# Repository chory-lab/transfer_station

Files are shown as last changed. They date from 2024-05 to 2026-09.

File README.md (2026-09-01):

[comment]: <> (Author: Benjamin Pyatski)
[comment]: <> (Company: Chory Lab)

<h1>Introduction</h1>
This repository holds the code (and previously used test code) for the functioning of the transfer system, or just the step motor rail. There are two parts to this README detailing the software components, and the hardware components of the transfer station system.

<h2>SD Card Setup</h2>

This branch publishes a complete, CI-audited Raspberry Pi OS image with the
application, Redis, frozen Python environment, systemd service and isolated
network configuration already installed. The flashers verify its SHA-256.

<h3>Windows</h3>

Insert the SD card, then paste into an <b>Administrator</b> PowerShell:

```powershell
irm https://raw.githubusercontent.com/chory-lab/transfer_station/main/pi-image/bootstrap.ps1 | iex
```

To select a physical disk number explicitly, download the script first:

```powershell
irm https://raw.githubusercontent.com/chory-lab/transfer_station/main/pi-image/bootstrap.ps1 -OutFile bootstrap.ps1
.\bootstrap.ps1 -DiskNumber 3
```

The media can be blank. Requires
<a href="https://www.raspberrypi.com/software/">Raspberry Pi Imager</a> to be
installed; Imager writes and verifies the complete prebuilt image.

<h3>macOS / Linux</h3>

Insert a removable SD card or USB drive and run:

```bash
curl -fsSL https://raw.githubusercontent.com/chory-lab/transfer_station/main/pi-image/bootstrap.sh | sudo bash
```

On macOS, install
<a href="https://www.raspberrypi.com/software/">Raspberry Pi Imager</a> first;
the script uses it to write and verify the selected external disk. Linux uses
the standard <code>lsblk</code>, <code>xz</code>, and <code>dd</code> tools.

<h3>Then: wire up the controller PC</h3>

The script asks which removable device to erase, downloads the audited sdm
image, verifies its checksum, and writes it. <b>No internet is needed on the
Pi.</b>

The Pi is reachable only over a private wired link, and <b>nothing on that
link hands out addresses</b>, so the controller PC's wired adapter must be
given a static address. Connect an Ethernet cable between the PC and the Pi,
then give the PC's wired adapter any address in <code>192.168.10.0/24</code>
except <code>192.168.10.1</code> (the Pi itself) &mdash; the convention is
<code>192.168.10.2</code> &mdash; with <b>no gateway and no DNS</b>. Leave
the PC's Wi-Fi or other adapters alone so it keeps its own internet.

Windows (Administrator PowerShell; replace <code>Ethernet</code> with the
wired adapter name shown by <code>Get-NetAdapter</code>):

```powershell
New-NetIPAddress -InterfaceAlias Ethernet -IPAddress 192.168.10.2 -PrefixLength 24
```

macOS (replace <code>en5</code> with the wired interface from
<code>networksetup -listallhardwareports</code>):

```bash
sudo ifconfig en5 192.168.10.2/24
```

Linux (replace <code>eth0</code> with the wired interface from
<code>ip -br link</code>):

```bash
sudo ip addr add 192.168.10.2/24 dev eth0
```

The Pi then comes up at:

```
http://192.168.10.1:5000        ssh chorylab@192.168.10.1
```

This branch currently uses the image build credential. Until the
<code>PI_PASSWORD</code> repository secret is configured and a new image is
published, the password is <code>changeme</code>. Change it after login.

<blockquote>
The image targets a Pi 4 Model B and works from SD or USB mass storage when
the Pi EEPROM permits USB boot. Do not apply Raspberry Pi Imager OS
customisation: the image is already configured. See
<a href="pi-image/README.md">pi-image/README.md</a> for internals and limits.
</blockquote>

<h2>Software</h2>
This section details the usage of the code.

<h3>api_step_motor.py</h3>
The system is setup in such a way where the majority of the fucntional code is in api_step_motor, which creates a UI through flask (and handles subsequent interactions with said UI) that the user can input commands to. 

<h3>A4988.py</h3>
In order for the stepper motor to connect to the Raspberry Pi 4 it is necessary to utilize a A4988 controller, and the python file of the same name holds all the function definitions utilized in api_step_motor.py and the microswitches, and handles the connection between the Raspberry Pi 4 and the stepper motor on the rail.

<h3>FLow Chart</h3>



<h2>Manual Setup (alternative to flashing)</h2>

<h3>Installation</h3>

* Install flask (make sure it is ver 2.2.2 or newer otherwise --app feature won't work, check this by running flask --version):
  
    ```pip install --upgrade Flask ```

* Install reddis:

    ```pip install redis```

* Install flask_caching:
  
    ```pip install flask_caching```

<h3>Setup (Skip if setup already running)</h3>
The first step is to get start the flask and redis server, the redis server handling multiple calls at the same time to allow asynchronous running of the code. 
<br><br>

1. Activate the Virtual Environment
    - Navigate to the location of the virtual environment:
    
      ```cd /home/git/transfer_station```
    - Activate the virtual environment:
    
      ```source foobar/bin/activate```
    
2. In another terminal, start the redis server:
   
    ```redis-server```  

4. Run the code through flask (on the previously setup virtual environment) and open the outputted link (first one is for the local machine, second is for a different machine on the same wifi):

    ```flask --app api_step_motor run --host=0.0.0.0```

<h2>Hardware</h2>
The hardware can be categorized into two parts, the actual circuitry required to run the transfer station, and then the physical components that actually make up the parts of the transfer station itself. 

<h3>Transfer Station Circuitry</h3>
The transfer station consists of a step motor rail connected through a motor driver (A4988 Stepper Motor Driver) to a computer (Raspberry Pi Zero 2 W) on which the code is running. The wiring diagram can be seen below:

![image](https://github.com/chory-lab/transfer_station/assets/69654071/a2e29e91-b305-4fbc-8b5c-8c84075bc933)

<h4>A4988 Stepper Motor Driver</h4>

![image](https://github.com/chory-lab/transfer_station/assets/69654071/13c0050c-7d20-4bd9-b880-a7aa17810c33)

Pin Index:
  - ENA -> Enable pin. When low A4988 is enabled, when high A4988 is disabled
  - RES -> Reset pin
  - SLP -> Sleep pin (connected to RES so SLP triggers code RES)
  - STP -> Step. Reads how many steps requested for the step motor to take
  - DIR -> Direction.
  - VMT -> Energy supply to power step motor
  - GND -> Ground
  - 2B, 2A, 1A, 1B -> Control for Bipolar Step Motor (Power, Step, Direction)
  - VDD -> Power for A4988

<h4>Raspberry Pi Zero 2 W</h4>

![image](https://github.com/chory-lab/transfer_station/assets/69654071/397a1f29-71f6-4400-840c-6d2acba378ad)

![image](https://github.com/chory-lab/transfer_station/assets/69654071/97159fb8-87ad-45c7-b7d0-eb24ef14be5d)

Pin Index:
  - 2 -> 5V Power to supply A4988
  - 6 -> Ground
  - 15 -> GPIO22, programmable pin
  - 16 -> GPIO23, programmable pin
  - 18 -> GPIO24, programmable pin

Any GPIO can be used as they are all programmable

<h3>Transfer Station System</h3>
The system is composed of 4 core components, these consist of the tray, tray platform, step motor rail system, and the mount. All components were printed with PLA plastic, and default 3D printer settings. Screws used were the default ones that come with the Hamilton Star, and the default bolts that came with the incubator mount. 

<h4>Tray</h4>
This is holds the 96 well plate (or equivalent size) when delivering the plate to the incubator, and vice versa.

![image](https://github.com/chory-lab/transfer_station/assets/69654071/5e6d066a-dbb4-403d-9bdd-c4cc44f140a3)

<h4>Tray Platform</h4>
This raises the tray to the needed height for the incubator to be able to reach the plate.

![image](https://github.com/chory-lab/transfer_station/assets/69654071/3565bda2-becf-4eeb-828e-3ba721c507a8)

<h4>Stepper Motor Rail System</h4>
This comprises of a stepper motor, connected to a rail system (screw) that spins moving a cart that is already on the screw.

![image](https://github.com/chory-lab/transfer_station/assets/69654071/2178c803-b7bc-447f-a207-de881839ab26)

<h4>Mount</h4>
This is what the stepper motor rail system is screwed onto connecting/supporting the stepper motor rail system on the incubator.

![image](https://github.com/chory-lab/transfer_station/assets/69654071/8c9b438e-2e05-4f78-83f6-389a6350ffdf)

<h4>Assembly</h4>
The final assembly consists of:

  1. Screw mount onto incubator with M6 x 12mm screws (x2)

  2. Screw stepper motor rail system to the mount with M3 x 12mm screws (x4)
  
  3. Screw tray platform onto cart with M4 x 8mm screws (x4)
  
  4. Slide tray onto pegs on tray platform
  
![image](https://github.com/chory-lab/transfer_station/assets/69654071/2ea4342a-1d0f-4a60-ac54-e75c83075aa1)

![IMG_2489](https://github.com/chory-lab/transfer_station/assets/69654071/6cb466e3-b27b-4c4f-b220-d72cb4b66d85)

<h2>Parts List</h2>
1. 3D Printed Pieces

  - Mount
  
  - Tray

  - Tray Stand
<br>
2. Screws

  - M6 x 12mm (x2) -> Used for screwing mount onto incubator
    - https://www.amazon.com/PZRT-Hexagon-Socket-Countersunk-Stainless/dp/B08DF82569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

  - M4 x 8mm (x4) -> Used for screwing tray platform onto cart
    - https://www.amazon.com/Socket-Screws-Metric-Machine-Threaded/dp/B0969NLFKW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

  - M3 x 12mm (x4) -> Used for screwing rail onto mount
    - https://www.amazon.com/SUNXULIMI-Socket-Furniture-Stainless-Threaded/dp/B0CMDVK2QK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
<br>

3. A4988 Stepper Motor Drive -> Needs seperate power cable
  - https://www.amazon.com/WWZMDiB-Stepstick-Stepper-Printer-Suitable/dp/B0BFQZWT6R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
<br>

4. Raspberry Pi Zero 2 W -> Needs seperate power cable, and male header pins to solder on
  - https://www.amazon.com/Raspberry-Quad-core-Bluetooth-onboard-Antenna/dp/B0CCRP85TR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

5. Stepper Motor Rail System
  -  https://www.amazon.com/FUYU-Linear-Module-Actuator-Stepper/dp/B0CG5PPKXY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

6. Powered USB hub with mini USB connector -> Used for connecting keyboard and mouse to raspbery pi zero 2 w
  - https://www.amazon.com/AuviPal-Adapter-Playstation-Classic-Raspberry/dp/B083WML1XB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

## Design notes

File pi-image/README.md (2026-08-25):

# pi-image

Builds a ready-to-flash Raspberry Pi image with the application, its
dependencies, an autostarting service, and an isolated static-IP ethernet
link all baked in.

Flash it and switch the Pi on. There is no first-boot provisioning, no
two-stage boot, and **the Pi never needs a network**.

## Why this shape

The obvious approach is to flash stock Raspberry Pi OS and configure it on
first boot. We built that first, and it cost us: a `systemd.run=` hook whose
path depends on the OS release, Windows volumes that sometimes have no drive
letter, CRLF mangling the shebang of the first-boot script, a Pi with no RTC
whose clock made `apt` reject repositories, and a 23 MB dependency bundle to
avoid needing internet on the device.

Every one of those problems exists only because work was deferred to the
device. Doing it at build time, in a chroot on a machine that can be tested,
deletes the entire category.

[`sdm`](https://github.com/gitbls/sdm) does the image customisation. It
already handles the account wizard, cloud-init, `machine-id`, root expansion
and the rest — the things we would otherwise rediscover one bug at a time.

## Building

```bash
sudo PI_PASSWORD='your-password' ./pi-image/build.sh
```

Produces `transfer-station-YYYY-MM-DD.img.xz` (currently about 900 MB). Flash it with
Raspberry Pi Imager, with **no customisation** — this image already has it.

CI builds and audits the final compressed image on every relevant push. Main
publishes the rolling `pi-image` release; the top-level README flashers
download that exact asset and verify its checksum.

## Configuring

Everything project-specific is in [`pi-app.env`](pi-app.env). That file is
the entire interface:

| Key | Meaning |
|---|---|
| `APP_NAME`, `PI_HOSTNAME`, `PI_USER` | identity |
| `REPO_DEST` | where the app is installed |
| `APT_PACKAGES` | system packages (C extensions, services) |
| `APP_EXEC` | the command the service runs; `${VENV}` and `${SERVER_PORT}` are substituted |
| `ETH_*`, `SERVER_PORT` | the isolated link |

Pure-Python dependencies come from `pyproject.toml` and are installed from
the hash-pinned `uv.lock` with `uv sync --frozen`
into a venv built on the system interpreter with `--system-site-packages` so
apt's prebuilt `RPi.GPIO` stays importable.

> **Never commit a real password.** This repository is public. Pass
> `PI_PASSWORD` in the environment, or set `PI_SSH_PUBKEY` and use a key.

## Using it for another instrument

Copy `pi-image/` and write a new `pi-app.env`. `build.sh`, `cscript.sh` and
the CI workflow are project-agnostic; only the manifest changes.

## The isolated link

`eth0` gets a static address with **no gateway and no DNS**, plus
`never-default=true` and IPv6 disabled. Without a default route on that
interface the Pi cannot reach, or be reached from, the lab LAN — only hosts
plugged into the same switch.

The controller PC needs a static address on the same subnet with no gateway
(e.g. `192.168.10.2/24`). Leave its normal Wi-Fi/LAN adapter alone so it
keeps its own default route and stays online.

## How it works

`build.sh` downloads the official Raspberry Pi OS Lite image, renders the
service unit and NetworkManager profile from the manifest, and hands the lot
to `sdm`, which runs [`cscript.sh`](cscript.sh) in three hooks:

- **phase 0** — on the host, image mounted at `$SDMPT`. Copies the repo, the
  service unit and the network profile in.
- **phase 1** — inside the image under `nspawn`. Installs `uv`, builds the
  This hook is deliberately empty because sdm has not created the user or
  installed apt packages yet.
- **post-install** runs inside the image after sdm's plugins. It installs
  `uv`, performs `uv sync --frozen`, verifies the imports, and enables the
  service and SSH.

Then the image is compressed, decompressed again, mounted, and audited before
publication. CI checks the real filesystem, packages, venv, enabled services,
boot layout and the no-gateway/no-DNS static network profile.

## Limits

- Linux only. `sdm` mounts and chroots into the image.
- Needs `qemu-user-static` binfmt for aarch64 when building on x86.
- The venv is built under emulation, so `RPi.GPIO` is checked by spec rather
  than imported — it raises on non-Pi hardware by design.
- Updating a deployed Pi means either re-flashing or copying files over SSH.
  SSH is enabled precisely so re-flashing is not the only option.

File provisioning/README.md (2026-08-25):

# Transfer Station SD card provisioning

Turns a stock Raspberry Pi OS Lite image into a ready-to-run transfer station:
the repo installed, the Flask server started automatically at boot, and `eth0`
pinned to a static address on an **isolated** ethernet segment.

## What you end up with

| | |
|---|---|
| UI | `http://192.168.10.1:5000` |
| SSH | `ssh chorylab@192.168.10.1` |
| Server | `systemd` unit `transfer-station.service` (auto-restarts on failure) |
| Logs | `journalctl -u transfer-station -f` |

`eth0` gets a static address with **no gateway and no DNS**. Without a default
route on that interface the Pi cannot reach — and cannot be reached from — the
lab LAN. It is visible only to hosts plugged into the same switch.

Edit `config.env` before flashing to change the address, port, hostname or
password.

## Flashing

### Windows

Flash the base image with Raspberry Pi Imager first, then:

```powershell
.\provisioning\flash.ps1
```

It finds the card by looking for the FAT32 volume that has a `cmdline.txt` in
it. Pass `-BootDrive E:` when more than one card is attached and you want to
name the right one; `E:` is the small FAT partition Windows mounts after
imaging (the one with `config.txt` and `cmdline.txt` in it).

#### If the boot partition has no drive letter

Windows does not always assign one. Disk Management then shows the partition
under its `bootfs` label with the drive-letter column blank, and nothing --
not `tar`, not PowerShell's own `New-Item` -- can write to it, because the
only path it has is a `\\?\Volume{GUID}\` path that those tools reject.

Both `flash.ps1` and `bootstrap.ps1` still *find* such a card, and will assign
a free letter themselves if PowerShell was started with **Run as
administrator**. Without elevation they stop and say so; assign the letter by
hand instead:

> Win+X -> Disk Management -> right-click the `bootfs` partition ->
> Change Drive Letter and Paths -> Add -> OK

### Which image, and Raspberry Pi Imager's customisation

Lite 64-bit is the intended base, but Desktop and Full work too -- nothing
here depends on the absence of a GUI.

Current Imager versions provision through **cloud-init**: applying any OS
customisation writes `user-data`, `meta-data` and `network-config` to the boot
partition and appends `ds=nocloud;...` to `cmdline.txt`. That is compatible
with the two-stage flow, but cloud-init runs *after* stage A and wins wherever
the two overlap:

| Setting | Winner on a customised card |
|---|---|
| hostname | Imager's, not `PI_HOSTNAME` |
| account password | Imager's, not `PI_PASSWORD` |
| SSH enabled | both do it |
| isolated static IP | stage B (its profile has `autoconnect-priority=100`) |

So either leave Imager's customisation switched off and let `config.env` own
everything, or set it in Imager and treat `PI_HOSTNAME` and `PI_PASSWORD` as
ignored. Stage B is ordered `After=cloud-final.service`, so the two never
contend for the apt lock.

### Linux / macOS

```bash
# flash and provision in one go
sudo ./provisioning/flash.sh --image raspios-bookworm-arm64-lite.img.xz --device /dev/sdX

# or provision a card you already flashed
./provisioning/flash.sh --boot /media/$USER/bootfs
```

## Troubleshooting a failed first boot

Both stages write a log to the **FAT boot partition**, which mounts on any
machine. If a boot goes wrong, pull the SD card, put it in your laptop and
read:

```
transfer-station/firstrun.log    # stage A
transfer-station/provision.log   # stage B
```

Stage B also prints to the console, so an HDMI monitor shows it live.

If stage A or B fails, the Pi falls back to DHCP with SSH enabled. Note that
on the isolated switch there is **no DHCP server**, so it will land on a
link-local `169.254.x.x` address and be effectively unreachable — plug it back
into a router to recover it over the network.

## First boot: plug into the internet once

The card boots in three phases:

1. **Stage A** (`firstrun.sh`, no network) — creates the user, sets the
   hostname, enables SSH, unpacks the repo, arms stage B. Reboots.
2. **Stage B** (`provision.sh`, needs internet) — `apt` installs
   `redis-server` and `python3-rpi.gpio`, installs `uv`, builds the venv,
   installs the systemd unit, then writes the isolated static network config.
   Reboots.
3. **Normal operation** — isolated static IP, server running.

Stage B is the only step that needs internet, so **give the Pi a normal
router/switch connection for the first boot**. It takes a few minutes. Once it
reboots into phase 3 you can move it to the isolated switch permanently.

If stage B can't reach the internet it exits with a clear error and retries on
the next boot — nothing is lost, just reconnect and reboot.

## Controller PC setup

Give the NIC facing the switch a static address on the same subnet, no gateway:

```
address 192.168.10.2
netmask 255.255.255.0
gateway <blank>
```

Leave your normal Wi-Fi/LAN adapter alone — it keeps the default route, so the
PC keeps internet while talking to the Pi over the switch.

## Python environment

`uv` manages the pure-Python deps in `pyproject.toml` and the frozen `uv.lock`.
The venv is built on
the **system** interpreter with `--system-site-packages`, so the apt-provided
`RPi.GPIO` C extension stays importable:

```bash
uv venv --python /usr/bin/python3 --system-site-packages .venv
UV_PROJECT_ENVIRONMENT=.venv uv sync --frozen --no-dev
```

To update deps on a running unit:

```bash
cd /home/chorylab/transfer_station
UV_PROJECT_ENVIRONMENT=.venv uv sync --frozen --no-dev
sudo systemctl restart transfer-station
```

The old `foobar/` venv (Python 3.7.3) is not used by the image and can be
ignored.

## Tests

```bash
provisioning/tests/run-all.sh              # host-safe suites
sudo provisioning/tests/run-all.sh         # + loopback SD card write
pwsh provisioning/tests/test_flash_ps1.ps1 # Windows flasher
```

| Suite | Runs | Covers |
|---|---|---|
| `test_flash_inject.sh` | anywhere | `cmdline.txt` hook, release detection, idempotence, payload staging, LF endings, tar excludes, arg validation |
| `test_flash_image.sh` | Linux + root | real MBR/FAT32 image written to a loopback "SD card" via `dd`, partition discovery, mount, on-card contents |
| `test_flash_ps1.ps1` | Windows | same properties as the bash injector, plus **byte-for-byte parity** of the generated `cmdline.txt` |
| `test_firstrun.sh` | container | stage A executed for real: account, groups, sudoers, hostname, repo extraction, stage B arming, self-disarm, password redaction |
| `test_rpios_chroot.sh` | Linux + root | the whole chain inside the **official Raspberry Pi OS rootfs** under qemu-user: real `archive.raspberrypi.com`, real package versions, real filesystem layout. Also asserts the image's own `/etc/fstab` really does mount the FAT partition at `/boot/firmware` |
| `test_deploy.sh` | container | generated unit, isolated network profile (asserts **no** `gateway=`/`dns=`), and the Flask server answering HTTP using the unit's real `ExecStart` |

The destructive suites create users and rewrite `/etc`, so they refuse to run
without `TS_ALLOW_DESTRUCTIVE=1` and are intended for a disposable container.

The deployment smoke test shims `RPi.GPIO` via `PYTHONPATH` (the real module
raises on non-Pi hardware) and runs a real `redis-server`, so it genuinely
exercises the app's import chain, the Redis-backed cache and template
rendering from the packaged `templates/` directory. A separate native job
always sends a short motion command and verifies the A4988 pin sequence.

## CI

`.github/workflows/image.yml` runs four jobs: static analysis, the Linux flash
pipeline (including the loopback image write), the Windows flash pipeline, and
the full stage A → stage B → deployment chain inside an **arm64 Debian
bookworm container** under QEMU.

That container is *Debian arm64, not Raspberry Pi OS* — it has no
`archive.raspberrypi.com` apt sources, so package versions differ from the real
device. It validates the logic and dependency resolution, not device fidelity.

### What CI still does *not* catch

The suites cover the *contents* of `cmdline.txt` and the payload, but nothing
in CI actually boots:

- The kernel honouring `systemd.run=` — no bootloader is involved
- `systemd` actually running the units (both stages stub `systemctl`)
- NetworkManager actually applying the profile to a real NIC
- Raspberry Pi OS's own apt archive and package versions
- Anything GPIO, driver or motor related — no hardware, and `RPi.GPIO` is
  shimmed

A test flash onto a spare SD card remains the only real validation of the boot
and network path.

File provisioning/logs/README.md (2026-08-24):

# Captured provisioning logs

Real logs pulled off a card's FAT boot partition, kept here so the two stages
can be compared against a known-good run. Both stages write their log to
`transfer-station/` on that partition, which mounts on any machine — pull the
card and read it there when a boot goes wrong.

## `firstrun-2026-08-24.log`

Stage A, complete and successful.

| | |
|---|---|
| Image | Raspberry Pi OS 64-bit **Desktop**, `Raspberry Pi reference 2026-06-18` (pi-gen stage4) |
| Customised in Imager | yes — cloud-init `user-data` on the card (user `chorylab`, hostname `transferstation`, SSH on) |
| Host | Windows, card flashed with `flash.ps1` |

Things in it that look alarming but are not:

- **`usermod: no changes`** — the account already existed. Stage A runs before
  cloud-init, but this card had been booted once already, so cloud-init had
  created `chorylab` on that earlier boot. Stage A is idempotent here.
- **`tar: … time stamp … is 5860264 s in the future`**, once per repo entry —
  the Pi has no RTC and stage A runs before any network, so its clock is still
  at the image build date and every file in `repo.tar.gz` looks
  future-dated. Extraction succeeds regardless.

Stage A then self-disarmed correctly: `systemd.run=` stripped back out of
`cmdline.txt`, `userconf.txt` deleted, `firstrun.sh` and `repo.tar.gz` removed
from the payload directory.

## No `provision.log` alongside it

Stage B left no log on this card. The card was flashed from a `provision.sh`
that predates `1d4b399`, which added `trap 'sync' EXIT` — without it the log
sits in the page cache and the `systemctl reboot` at the end of stage B
discards it. Cards flashed after that commit should keep their stage B log.

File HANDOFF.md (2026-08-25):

# Transfer Station — session handoff, 24 Aug 2026

Provisioning a Raspberry Pi 4B to run the stepper-rail server on an isolated
ethernet segment. **Stage A now works on real hardware. Stage B does not run,
and nobody has seen it fail** — that is the open question.

| | |
|---|---|
| Branch | `main`, plus `sdm-image-builder` (not merged) |
| Hardware | Raspberry Pi 4 Model B |
| Target | `http://192.168.10.1:5000`, `ssh chorylab@192.168.10.1` |
| Bundle | published, pinned to Trixie |

---

## Start here

The Pi is on the bench with a monitor. It boots fine, stage A completed, and
there is **no `provision.log` anywhere** — so stage B either never ran or died
before it could write one. Two commands at the Pi console settle it:

```bash
# why didn't stage B run?
systemctl status transfer-station-provision
journalctl -u transfer-station-provision --no-pager

# run it by hand, output straight to screen
sudo /usr/local/sbin/transfer-station-provision
```

The last line is the fast path: it runs stage B in the foreground, so the log
file is irrelevant. If it completes, the Pi reboots onto the static address
and the job is done.

---

## What the instrument is

A NEMA stepper on a linear rail, driven through an A4988 from a Pi 4B.
`api_step_motor.py` serves a Flask UI whose buttons jog the rail; `A4988.py`
does the stepping. Redis backs flask-caching, which is how the stop button
reaches a move already in progress.

The Pi must sit on an ethernet segment reachable from a controller PC over a
switch, but **not** from the lab LAN. That means one static address with no
gateway and no DNS — without a default route on that interface it cannot
bridge the two networks.

`api_step_motor.py` hardcodes `/home/chorylab/transfer_station/templates`, so
the account name and install path are load-bearing.

---

## Where it stands

"Proven" means observed working on hardware, not "the tests pass".

| Link in the chain | State | Evidence |
|---|---|---|
| Card builds from one command | proven | built on the lab PC |
| Firmware reads `cmdline.txt` | proven | stage A ran on hardware |
| `systemd.run=` fires stage A | proven | `firstrun.log` on the card |
| Account, hostname, SSH, repo unpack | proven | same log |
| Reboot into stage B | unclear | Pi reboots, but no stage B log |
| Stage B installs deps | unproven | works in CI, never on hardware |
| Static IP applied to a real NIC | unproven | Pi is not at `.1` yet |
| Server reachable over the switch | unproven | blocked on the above |
| Motor moves at the new step rate | unproven | needs the rail |

Everything above the break was broken this morning and is fixed. One bug
caused all of it — see "the boot-path bug" below.

---

## Open threads

### BLOCKING — stage B leaves no trace

No `provision.log` on the card, and the Pi boots normally. Two candidates;
the console commands above distinguish them.

**Candidate 1, now fixed.** `provision.sh` sourced its config *before*
setting up logging, so under `set -euo pipefail` a missing
`/usr/local/share/transfer-station-config.env` killed it with no output
anywhere. Fixed in `7fc0209`. But **the card on the bench carries the old
copy**, so re-flash or copy the new `provision.sh` across before concluding
anything from its behaviour.

**Candidate 2, unchecked.** The unit never ran at all — `ConditionPathExists`
unmet, or stuck behind `network-online.target` / `cloud-final.service`, which
it is ordered after. `systemctl status` says which.

### UNKNOWN — does that card carry the offline bundle?

Nobody checked. `ls /boot/firmware/transfer-station/` answers it. If
`bundle/` is present, stage B was never waiting on internet and the network
theory is dead. If absent, re-running the one-liner now stages it — that gap
was fixed in `0c79017`.

### CHECK FIRST — controller PC addressing

The switch has no DHCP. For the PC to reach `192.168.10.1`, its NIC on that
switch needs a static address in the same subnet (e.g. `192.168.10.2/24`, no
gateway). Reported as already configured; worth one `ipconfig`, since it
fails silently.

### RESOLVED — the boot-path bug that wasted a day

Real pi-gen `issue.txt` carries **no codename** — only a build date and the
pi-gen commit. Release detection matched `bookworm|trixie|forky`, which never
matches a real card, so every image got the pre-Bookworm `/boot` path and
`systemd.run=` pointed at a file that does not exist. Stage A could never run.

The test fixtures had the codename baked in, so the suite *confirmed* the bug
rather than catching it. Detection now keys off the build date against
Bookworm's release date, in all four places it appears.

---

## The other direction — branch `sdm-image-builder`

Late in the session the conclusion was that provisioning on first boot is the
wrong shape. Every problem hit today — boot-path detection, Windows volume
discovery, CRLF mangling the shebang, a clock with no RTC breaking apt, a
23 MB bundle to avoid needing internet — exists **only** because work was
deferred to the device.

`pi-image/` on that branch bakes everything at build time using
[sdm](https://github.com/gitbls/sdm), producing a `.img.xz` you flash and
switch on. No two-stage boot, no `systemd.run=` hook, no bundle.
`pi-app.env` is the whole per-project interface, so **syringe_pump** would
need only its own copy of that file.

Status: the manifest lint job passes, the image build fails. First failure was
`--timezone`, which is not an sdm switch — removed, timezone now set in the
phase script instead. Expect one or two more of those.

Nothing on `main` was touched, deliberately. The bench card works and should
keep working until an sdm-built image boots a real Pi.

---

## CI

GitHub Actions was **disabled** on this repo until today, so any run predating
that does not exist.

| Job | Branch | State |
|---|---|---|
| static analysis | main | fixed, rerunning |
| flash pipeline (linux) | main | green |
| flash pipeline (windows) | main | green |
| provisioning on real Raspberry Pi OS (chroot) | main | green |
| offline dependency bundle | main | green, published |
| manifest and scripts | sdm-image-builder | green |
| build the image | sdm-image-builder | **failing** |

The bundle is a release asset at
`releases/latest/download/offline-bundle.tar.gz` — 23 MB, 7 debs, 11 wheels,
pinned to the Trixie image its `.debs` came from. A mismatched release is
refused rather than half-installed.

`PI_PASSWORD` is **not** set as a repository secret. Until it is, CI-built
images bake in `changeme`.

---

## Things that will bite you

- **Tests can confirm a bug.** The fixtures encoded the same wrong assumption
  as the code. Check a fixture against the real artifact before trusting a
  green suite.
- **`grep -P` is not universal.** A control-character check using it silently
  passed a file full of control characters — a failing `-P` with stderr
  redirected is indistinguishable from "no matches". Detectors now self-test
  against known-bad input first.
- **Escape sequences get mangled through editing layers.**
  `provisioning\flash.ps1` became `provisioning<FF>lash.ps1`;
  `.\bootstrap.ps1` in the README became `.<BS>ootstrap.ps1`. Both invisible
  in a diff, both shipped. `test_no_control_chars.sh` guards this now.
- **`Get-Volume` lies about `FileSystem`.** It returns empty for perfectly
  good partitions, so filtering on `FAT32` hid a correctly flashed card. Test
  for `cmdline.txt` instead. Windows also sometimes assigns no drive letter at
  all.
- **A Pi has no RTC.** With no network it booted 68 days behind, which makes
  apt reject repositories as "not valid yet". The flashers now stamp the build
  time and stage A advances the clock.
- **Both stage logs live on the FAT partition** (`transfer-station/*.log`),
  readable from any machine. Fastest diagnostic when the Pi is uncooperative.
  `.prev` copies survive a re-flash.

---

*State above was verified against the repo and CI at the end of the session,
not recalled. `main` at `7fc0209` plus a shellcheck fix.*

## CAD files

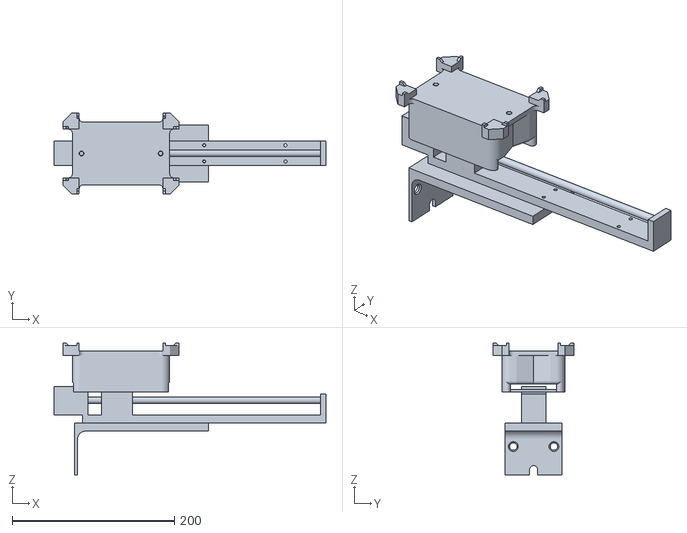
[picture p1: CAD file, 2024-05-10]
3D Files/Assembly.stl
335.0 x 100.0 x 162.5

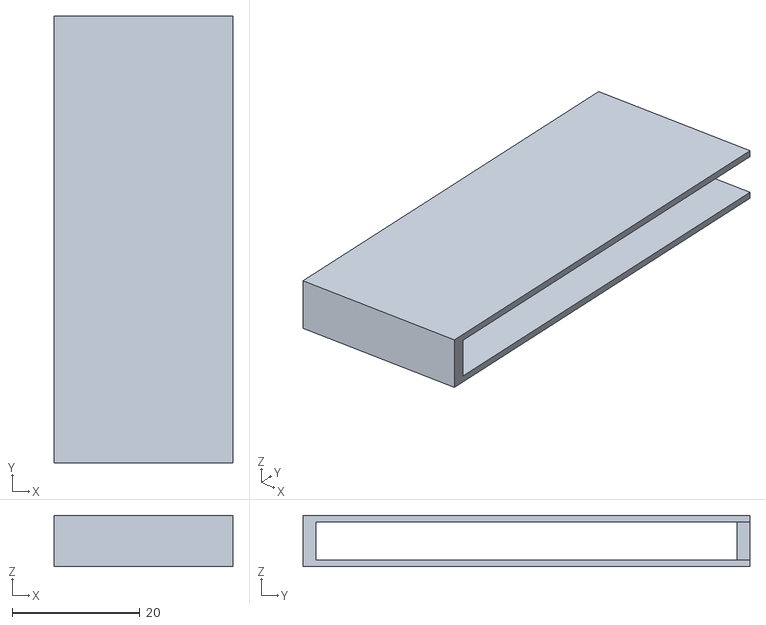
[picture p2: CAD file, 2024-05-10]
3D Files/Pi Zero Enclosure.stl
28.0 x 70.0 x 8.00

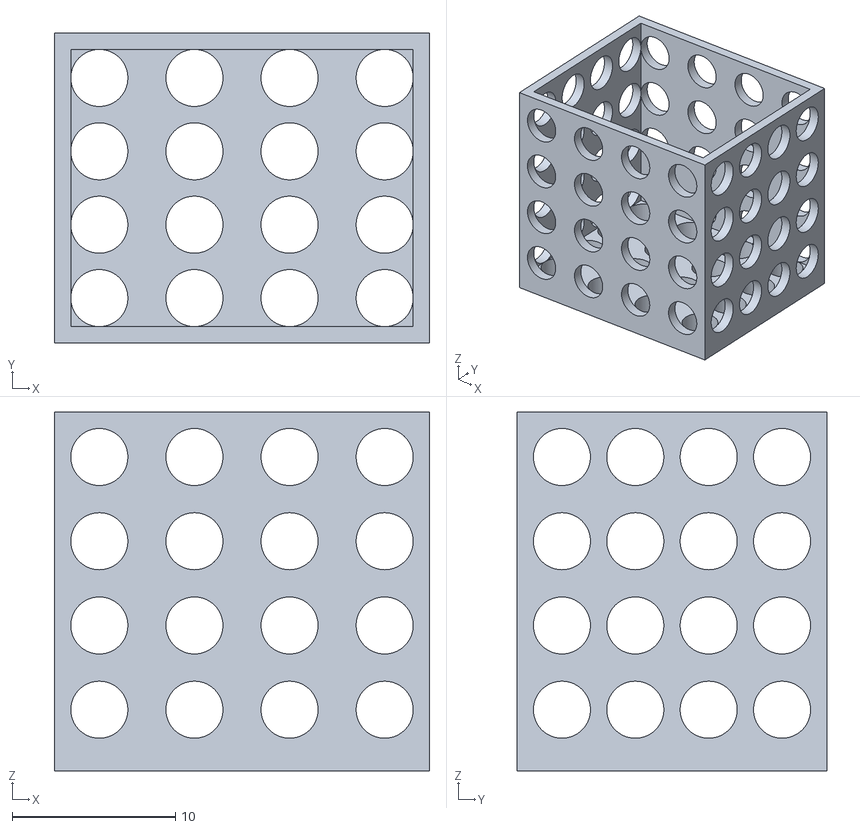
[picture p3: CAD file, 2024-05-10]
3D Files/A4988 Enclosure.stl
23.0 x 19.0 x 22.0

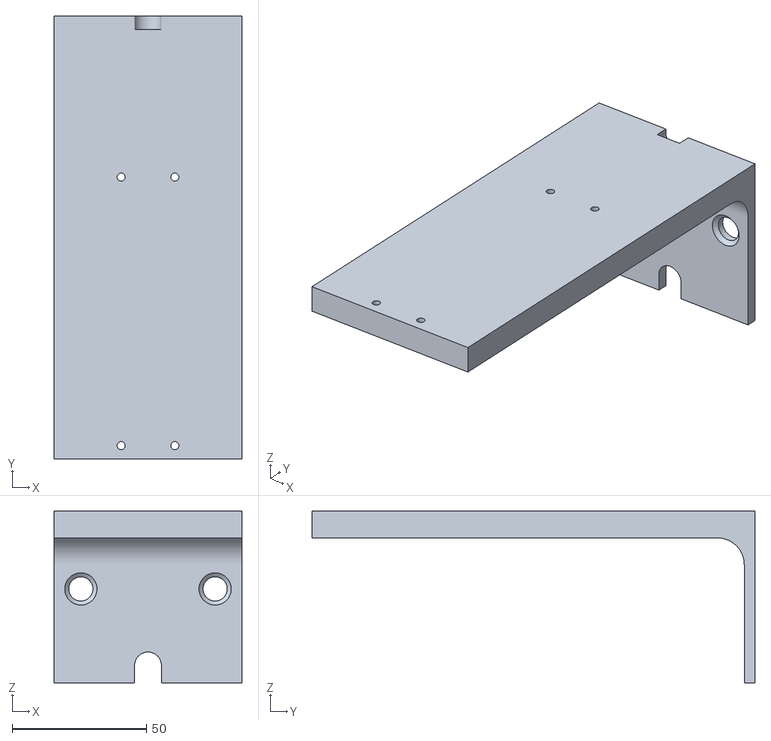
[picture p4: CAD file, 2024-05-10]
3D Files/Mount.stl
70.0 x 165.0 x 64.0

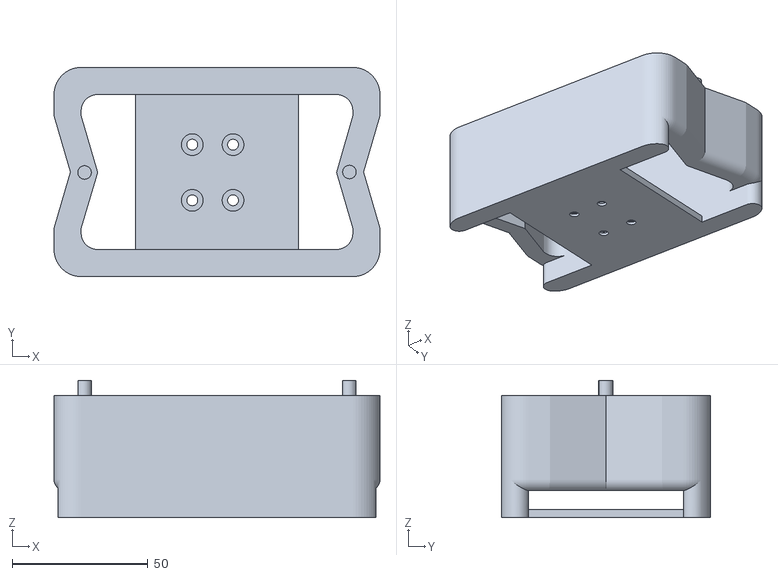
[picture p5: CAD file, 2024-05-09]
3D Files/Tray Platform.stl
120.0 x 77.0 x 50.5

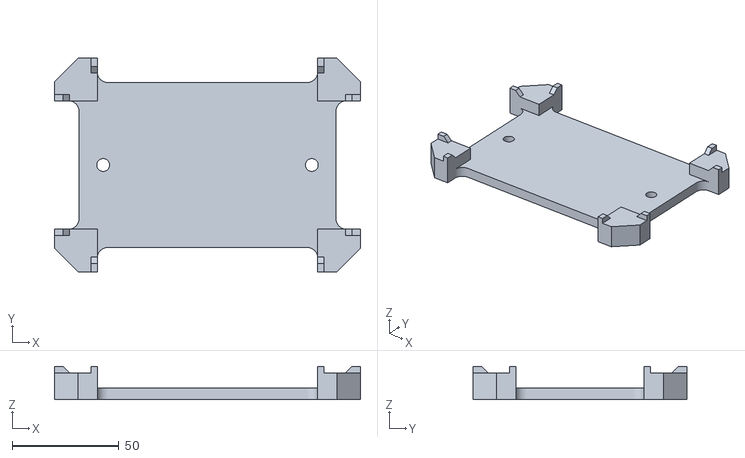
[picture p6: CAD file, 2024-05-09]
3D Files/Tray.stl
143.0 x 100.0 x 15.5

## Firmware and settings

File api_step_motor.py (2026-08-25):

#Author: Benjamin Pyatski
#Company: Chory Lab

import os
from flask import Flask, render_template, request, jsonify
import RPi.GPIO as GPIO
import time
from flask_caching import Cache
import redis
import A4988    

print(__name__)
app = Flask(__name__, template_folder=os.path.join(os.path.dirname(__file__), 'templates'))
app.config['CACHE_TYPE'] = 'RedisCache' 
cache = Cache(app)

bool_to_string = {True:'True', False: 'False'}
string_to_bool = {'True':True, 'False': False, None: None}

################################
# RPi and Motor Pre-allocations
################################

#GPIO.setmode(GPIO.BOARD)

#define GPIO pins
direction= 22 # Direction (DIR) GPIO Pin
step = 23 # Step GPIO Pin
EN_pin = 24# enable pin (LOW to enable)

# Declare a instance of class pass GPIO pins numbers and the motor type
my_motor = A4988.A4988Nema(direction, step, (11,9,10), "A4988", cache)    

GPIO.setup(EN_pin,GPIO.OUT) # set enable pin as output

cache.set('motor_stop', 'False')

opened_page = cache.get('has_opened_page')
if opened_page == None:
    cache.set('has_opened_page', 'True')
    cache.set('motor_moving', 'False')

@app.route('/', methods=['GET', 'POST'])
def index():
    if request.method == 'POST':
        if request.form.get('stop_motor') == 'Stop Motor':
            cache.set('motor_stop', 'True')
            return render_template('buttons.html')
            
        #dropbox
        try:
            direction = string_to_bool[request.form['direction']]
        except:
            direction = True
    
        #hit boxes
        try:
            step_num = int(request.form['step_num'])         
        except:
            step_num = 26000
        try:
            step_delay = float(request.form['step_delay'])
        except:
            # Applied to both the high and low phase of each pulse, so the
            # step period is 2*step_delay -> 400 half-steps/s = 200 full
            # steps/s = 1 rev/s. Sits inside the A4988 pull-in region, so
            # the motor starts from rest without ramping and won't stall.
            step_delay = 0.00125
        
        #go left till end button
        if request.form.get('go_left') == 'Go Left' or request.get_data() == b'go_left':
            string = move_test(False, step_num, step_delay)
            return render_template('buttons.html')
        
        #go right till end button
        if request.form.get('go_right') == "Go Right" or request.get_data() == b'go_right': 
            string = move_test(True, step_num, step_delay)
            return render_template('buttons.html')
        
        #button
        if request.form.get('run_motor') == 'Run Motor':
            string = move_test(direction, step_num, step_delay)
            return render_template('buttons.html')
        
    elif request.method == 'GET':        
        return render_template('buttons.html')            

@app.route('/status')
def status():
    state = cache.get('motor_moving')
    return state

@app.route('/move_test')
def move_test(direction, step_num, step_delay):
    motor_moving = string_to_bool[cache.get('motor_moving')]
        
    if motor_moving:
        return "move_test already running"    
    else:
        cache.set('motor_moving', 'True')
        ###########################
        # Actual motor control
        ###########################
        #
        GPIO.output(EN_pin,GPIO.LOW) # pull enable to low to enable motor
        
        print("running motor")
        my_motor.motor_go(direction, # True=Clockwise, False=Counter-Clockwise
                        "Half" , # Step type (Full,Half,1/4,1/8,1/16,1/32)
                        step_num, # number of steps
                        step_delay, # step delay [sec]
                        True, # True = print verbose output 
                        .05) # initial delay [sec]
        GPIO.output(EN_pin,GPIO.HIGH)
        
        cache.set('motor_moving', 'False')
        
        return "Motor Running"
    
if __name__ == '__main__':
    app.run(host="0.0.0.0", port=5000, debug=True)

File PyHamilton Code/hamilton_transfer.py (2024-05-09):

#Author: Benjamin Pyatski
#Company: Chory Lab
#Purpose: Test basic movements of Hamilton Star through PyHamilton with integration of transfer_station system

import os
import sys
import serial

from pyhamilton import *

liq_class = 'StandardVolumeFilter_Water_DispenseJet_Empty'

lmgr = LayoutManager('Test_1.lay')

plate_1 = layout_item(lmgr, Plate96, 'Nun_96_Fl_HB_0001')
plate_2 = layout_item(lmgr, Plate96, 'Nun_96_Fl_HB_0002')
plate_3 = layout_item(lmgr, Plate96, 'Nun_96_Fl_HB_0003')

tip_carrier = (layout_item(lmgr, Tip96, 'HT_L_0001'))

tips = [(tip_carrier, x) for x in range(8)]
wells_1 = [(plate_1, x) for x in range(8)]
wells_3 = [(plate_3, x) for x in range(8)]
vols = [30 for x in range(8)]
a = serial.Serial("COM5", 9600, timeout=1)

#flask IP address
url = 'http://10.146.92.218:5000'

if __name__ == '__main__':

    with HamiltonInterface(simulate=True) as ham_int:
        normal_logging(ham_int, os.getcwd())
        initialize(ham_int)

        #send request to transfer_station raspberry pi through flask IP address
        requests.post(url, data='go_right')

        
        move_plate(ham_int, plate_1, plate_2, gripHeight=10.0, gripWidth=80.0, gripMode=0, widthBefore = 100.0)
        #  grip_height=6.0, gripWidth=80.0, gripMode=0, widthBefore = 100.0


        requests.post(url, data='go_left')

        a.write(bytes('mv:ts 010\r', encoding='utf-8'))
        # requests.post(url, data='go_right')
        # move_plate(ham_int, plate_2, plate_1, gripHeight=10.0, gripWidth=80.0, gripMode=0, widthBefore = 100.0)
        
        # tip_pick_up(ham_int, tips)
        # aspirate(ham_int, wells_1, vols, liquidClass="HighVolume_Water_DispenseJet_Empty")
        # dispense(ham_int, wells_3, vols, liquidClass="HighVolume_Water_DispenseJet_Empty")
        # tip_eject(ham_int, tips)
        # move_by_seq(ham_int, 'Nun_96_FL_HB_0004_lid', 'Nun_96_FL_HB_0001_lid', grip_height=6.0, gripWidth=80.0, gripMode=0, widthBefore = 100.0)

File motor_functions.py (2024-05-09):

#Author: Benjamin Pyatski
#Company: Chory Lab

from flask import Flask, render_template, request, jsonify
import RPi.GPIO as GPIO
import time
import os
import A4988
import redis

r = redis.Redis()

GPIO.setmode(GPIO.BCM)

#define GPIO pins
direction= 22 # Direction (DIR) GPIO Pin
step = 23 # Step GPIO Pin
EN_pin = 24# enable pin (LOW to enable)

# Declare a instance of class pass GPIO pins numbers and the motor type
my_motor = A4988.A4988Nema(direction, step, (11,9,10), "A4988")
GPIO.setup(EN_pin,GPIO.OUT) # set enable pin as output


GPIO.output(EN_pin,GPIO.LOW) # pull enable to low to enable motor

print("running motor")

clockwise = False
start = time.time()

GPIO.setup(4, GPIO.IN)

while(1==1):
    print(GPIO.input(4) == 0)

my_motor.motor_go(False, # True=Clockwise, False=Counter-Clockwise
                "Half", # Step type (Full,Half,1/4,1/8,1/16,1/32)
                2000, # number of steps
                0.001, # step delay [sec]
                True, # True = print verbose output 
                0.05) # initial delay [sec]

r.set('stop_motor', 'True')

my_motor.motor_go(True, # True=Clockwise, False=Counter-Clockwise
                "Half" , # Step type (Full,Half,1/4,1/8,1/16,1/32)
                2000, # number of steps
                0.001, # step delay [sec]
                True, # True = print verbose output 
                0.05) # initial delay [sec]

end = time.time()
print(end-start)

GPIO.output(EN_pin,GPIO.HIGH)

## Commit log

2024-03-12 updated api_step_motor and flask to work on other computers on same network
    [pyvenv.cfg]
2024-03-12 added go left till end and go right till end buttons to UI
2024-04-11 3D files for tray and lid
    [Tray and Lid (1).stl]
2026-08-24 Add Raspberry Pi image provisioning, tests, and CI
    Flashes this repo onto an SD card with the server autostarting at boot and
    eth0 pinned to an isolated static address.
    provisioning/
    flash.sh / flash.ps1 build a card on Linux/macOS or Windows. All
    provisioning goes through the FAT boot partition via the systemd.run=
    hook in cmdline.txt, so the Windows path never needs to write ext4.
    payload/firstrun.sh stage A, offline: account, hostname, SSH, repo
    unpack, arms stage B, then disarms itself.
    payload/provision.sh stage B, needs internet once: apt, uv, venv,
    systemd unit, then swaps eth0 to the isolated static config.
    The ethernet profile is static with no gateway an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
    [api_step_motor.py]
2026-08-24 Test provisioning against the real Raspberry Pi OS rootfs
    Replaces the Debian arm64 container job with a chroot into the official
    Raspberry Pi OS Lite arm64 image under qemu-user binfmt. Stage A, stage B
    and the deployment checks now run against genuine Raspberry Pi OS: its own
    apt archive, its own package versions, its own filesystem layout.
    The driver also asserts the image's /etc/fstab really does mount the FAT
    partition at /boot/firmware, which until now was an unverified assumption
    underpinning the systemd.run path in cmdline.txt.
    test_firstrun.sh gains TS_KEEP_BOOT so it can run against a real boot
    partition instead of a synthesised one, and its cmdline assertion is now
    image-agnosti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
2026-08-24 Document the SD card flashing workflow in the README
    Adds the automated setup path (config, flash on Windows or Linux/macOS, the
    one connected first boot, controller PC static IP, service management) ahead
    of the existing manual instructions, which are relabelled as the alternative.
    Also flags that the Raspberry Pi Zero 2 W in the parts list has no ethernet
    port, so the isolated static-IP link needs a Pi 4 or a USB ethernet adapter.
2026-08-24 Mirror provisioning logs to the boot partition
    Stage B previously logged only to the journal and console. The journal lives
    on ext4, so a failed provisioning boot left nothing readable from a Windows
    or macOS machine. Both stages now write to the FAT boot partition, which
    mounts anywhere, so pulling the card and reading provision.log is the fastest
    way to diagnose a bad first boot.
    Also records the Pi 4 Model B as the target hardware and notes that the
    parts list entry for a Zero 2 W is stale -- that model has no ethernet port.
2026-08-24 Warn against committing a real password to config.env
    This repository is public, so a password committed here would be published
    permanently in git history -- and it is the device's SSH login.
2026-08-24 Add one-command SD card builders and cut the README down
    bootstrap.sh and bootstrap.ps1 do the whole job from a single pasted line
    with no clone: they fetch the provisioning scripts and the OS image, ask
    which card to use and what password to set, then write and provision it.
    The README section is now two commands and a sentence about the first boot.
    The controller PC instructions are dropped -- it is assumed configured.
2026-08-24 Fix CI failures from the first real run
    - Shell scripts were committed without the executable bit (developed on
    Windows, where git does not track it), so tests could not invoke each
    other. Set the mode, and call helper scripts via bash so the bit is not
    load-bearing.
    - shellcheck SC2164: cd without an exit guard in test_deploy.sh.
    - test_deploy.sh fell back to a hardcoded /src path for config.env. stage B
    deletes the stashed copy when it disarms itself, so resolve the fallback
    relative to the test instead.
2026-08-24 Encode the provisioning password as base64
    config.env is sourced by bash on the Pi and parsed by PowerShell on the
    flashing host. A password containing | & $ ' or a backslash broke the bash
    source outright, taking every consumer down with it. Quoting for one parser
    risks breaking the other, so bootstrap now writes PI_PASSWORD_B64 and the
    consumers decode it. Hand-edited PI_PASSWORD still works unchanged.
    Adds test_bootstrap.sh, which found this: it asserts the raw.githubusercontent
    URLs quoted in the README resolve to files that exist, that the bootstraps
    hand off to the right flashers, that the advertised address matches
    config.env, and that a metacharacter password round-trips byte for by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
2026-08-24 Spell out which Raspberry Pi OS image to pick
    Lite is not in Imager's top-level list, so name the menu path. Note that
    Desktop and Full work too and that 64-bit is the part that matters.
2026-08-24 Stop the chroot suite failing on an emulation limitation
    redis-server does not start under qemu-user, so the HTTP smoke test could
    never pass in the chroot -- and the test suppressed redis's stderr, so the
    log said only that the server never answered.
    Redis now runs in the foreground with its output captured and printed, and
    when it cannot start under emulation the runtime checks are reported as
    skipped rather than failed. Outside emulation a dead redis is still a hard
    failure.
2026-08-24 Verify the card from the PC as part of provisioning
    bootstrap now runs verify-card at the end and refuses to declare success if
    the card is malformed. verify-card can also be run by hand afterwards: both
    stages leave logs on the FAT partition, so it reports how far the Pi got
    without needing the Pi.
    Fixes two real bugs found by running it:
    - flash.sh copied payload files verbatim while flash.ps1 normalised them, so
    a Windows or renormalised checkout shipped CRLF scripts to the Pi. A CR
    after the shebang makes firstrun.sh silently not run at all.
    - The CR checks themselves were unreliable: $'\r' degenerates to an empty
    grep pattern on git-bash, matching every line. Detection now uses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
2026-08-24 Write the OS from bootstrap.ps1 so Windows is one command too
    The card can now be blank: bootstrap.ps1 drives rpi-imager's CLI to write
    Raspberry Pi OS, waits for Windows to mount the boot partition, then
    provisions and verifies as before. If the card already has Raspberry Pi OS
    on it the write is skipped, so re-running is safe.
    Imager is a prerequisite rather than something to install on the fly -- it
    was already required to flash the card by hand. Its CLI is used instead of a
    hand-rolled raw disk write because it is the tested, verified path.
    Disk selection is restricted to USB/SD/MMC media that is neither the boot nor
    the system disk, and requires typing ERASE.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
2026-08-24 Fix card detection hiding the card
    Detection filtered volumes on FileSystem -eq 'FAT32', but Get-Volume reports
    that property inconsistently -- it can come back empty for a perfectly good
    partition, which silently hid a correctly flashed card. Reproduced locally:
    a real 117 GB removable partition reports no FileSystem and size 0.
    Detection now tests every visible drive letter for cmdline.txt, which is the
    actual signal, and combines Get-Volume with Get-PSDrive so one failing does
    not hide the card.
    When nothing is found it now prints the drives Windows can see, and
    -BootDrive lets the user point at the card explicitly.
2026-08-24 Find SD cards Windows gave no drive letter, and fix boot-path detection
    Three things stopped a freshly imaged card from provisioning on Windows.
    Windows does not always assign a drive letter to the FAT boot partition.
    Disk Management then shows it under its "bootfs" label with the letter
    column blank, and bootstrap.ps1 filtered those volumes out entirely, so a
    perfectly good card reported "No Raspberry Pi OS card found". A letterless
    volume is reachable only through its \?\Volume{GUID}\ path, which both
    New-Item and tar reject, so the fix is to assign a letter -- done
    automatically when elevated, with instructions to do it by hand otherwise.
    -BootDrive becomes optional now that the card can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
2026-08-24 Flush provision.log on every exit path
    sync ran only on the success path, so a failed provisioning boot could lose
    its log to the page cache if the Pi was powered off before writeback -- the
    exact case where the log is the only diagnostic available. A trap on EXIT
    now covers the no-internet exit and any set -e abort.
2026-08-24 Build an offline dependency bundle so the Pi needs no internet
    Stage B previously required one connected boot to apt-install redis and pip
    the Python deps. The card can now carry everything instead.
    build-bundle.sh runs inside the Raspberry Pi OS chroot, so apt's own solver
    resolves the arm64 dependency closure against the real archive -- the thing
    that made this fragile to attempt from Windows. It collects redis-server and
    python3-rpi.gpio with their dependencies, the uv aarch64 binary, and the
    pure-Python wheels, plus a manifest recording the release it was built for.
    provision.sh installs from the bundle when the card has one: dpkg -i over the
    full closure needs neither network nor solv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
2026-08-24 Ship the dependencies on the card so the Pi never needs internet
    Completes the offline path. CI publishes the bundle as a release asset, and
    both bootstraps download it and stage it on the card, so stage B installs
    everything locally and the connected first boot is gone.
    The bundle pins the exact OS image its .debs were built against, and the
    bootstraps write that image rather than "latest". Without pinning the
    releases drift apart, provision.sh refuses the mismatched bundle, and the Pi
    silently needs a network boot after all -- so the pin is what makes the
    guarantee hold.
    flash.ps1 gains -Bundle to match flash.sh's TS_BUNDLE. verify-card reports
    whether the card is self-contained, and say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
2026-08-24 Keep a real stage A log from a successful cloud-init card
    First boot that actually provisioned, off a Raspberry Pi OS 64-bit Desktop
    image (pi-gen 2026-06-18) customised in Imager, so the card carried
    cloud-init user-data. Worth keeping as the known-good reference: two lines
    in it read like failures and are not, and both cost time to work out.
    usermod reports "no changes" because cloud-init had already created the
    account on an earlier boot of the same card -- stage A runs before
    cloud-init but is idempotent over an account that exists. tar warns that
    every extracted file is ~68 days in the future because the Pi has no RTC
    and stage A runs with no network, so its clock is still at the image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
2026-08-24 Set the clock on first boot, and guard against mangled escapes
    Two fixes from the first successful stage A on real hardware.
    The Pi has no RTC, so with no network it booted believing the date was
    18 June while the card was built on 24 August -- 68 days behind. That is not
    just the noisy tar warnings in the log: apt rejects repositories whose
    Release file looks like it is from the future ("not valid yet"), and TLS
    validation can fail outright, so stage B could fail on the clock rather than
    on connectivity. The flashers now stamp the build time on the card and stage
    A advances the clock to at least that point before doing anything else.
    tar also extracts with -m so a skewed clock cannot bury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
2026-08-24 Reject carriage returns in LF-pinned shell scripts
    shellcheck failed with SC1017 on verify-card.sh: a comment describing a
    mangled \r escape had itself acquired a literal CR. The control-character
    guard did not catch it because CR was whitelisted -- CRLF files are
    legitimate in general, but never in a file .gitattributes pins to eol=lf.
    The guard now also rejects any CR in a tracked .sh file, and promptly caught
    one in its own comment.
2026-08-24 Ship the bundle to cards that already have Raspberry Pi OS
    The bundle fetch sat inside the branch that images a blank card, so a card
    already carrying Raspberry Pi OS -- the common case when someone flashed with
    Imager first -- silently got no bundle and still needed a connected boot.
    It now runs for every card, before the card is even inspected, and the
    manifest still supplies the pinned image URL for the case where we do write
    the OS.
    Also fixes verify-card reporting a correct card as broken: its release
    detection was a stale copy of the codename-only logic, so it expected the
    Bullseye path and failed the check that flash.sh had just satisfied. It now
    mirrors flash.sh's date-based detecti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
2026-08-24 Stop verify-card failing a card that is actually fine
    Re-flashing a card that had already booted made verification fail twice
    over, and bootstrap.ps1 throws on a failed verification, so a perfectly
    good card looked unusable.
    verify-card decides which phase a card is in from whether firstrun.log is
    present, since stage A deletes firstrun.sh when it succeeds. But flash.ps1
    left the previous boot's log in place, so a freshly armed card presented as
    firstrun.sh + firstrun.log and was reported "stage A started but did NOT
    complete" -- with the real checks skipped entirely, since those only run in
    the preboot phase. Both flashers now retire firstrun.log and provision.log
    to .prev when they re-arm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
2026-08-24 Add pi-image: build a ready-to-flash image instead of provisioning on boot
    A standalone utility, intended to serve both this instrument and
    syringe_pump. Everything is installed at build time, so the card needs no
    first-boot provisioning, no two-stage boot, and no network on the Pi.
    sdm does the image customisation. It already solves the account wizard,
    cloud-init, machine-id and root expansion -- the things the current
    provisioning layer rediscovered one bug at a time. Our own code is reduced
    to a two-phase cscript: stage the repo and rendered configs into the mounted
    image, then build the uv venv and enable the service inside it.
    pi-app.env is the whole per-project interface. A second in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
2026-08-24 Set up stage B logging before anything that can fail
    provision.sh sourced its config at line 15 but did not redirect output to the
    card until line 23. Under set -euo pipefail a missing or unreadable config
    killed the script before any log existed, producing exactly the symptom seen
    on the bench: the Pi boots fine and there is no provision.log at all, on the
    card or anywhere else.
    Logging is now the first thing the script does, and a missing config is an
    explicit error that lands in the log rather than a silent exit.
2026-08-24 Drop the sdm switches that do not exist
    --timezone is not an sdm switch; the first CI build failed on it. The
    timezone is now set in cscript phase 1, where it is a plain symlink and
    cannot be wrong. --restart is dropped too: it reboots at the end of first
    boot, which is not wanted and was included on the same guess.
2026-08-24 Actually remove --timezone and --restart from the sdm invocation
    The previous commit set the timezone in cscript but left the invalid switch
    in place, so the build would have failed in exactly the same way.
2026-08-24 Add a session handoff for the next person at the bench
    Records what is proven on hardware versus only in CI, the two console
    commands that answer why stage B leaves no log, and the gotchas that cost
    real time today.
2026-08-24 Give the phase script its manifest, and test that it gets it
    sdm copies cscript.sh into the image and runs it from there, so the
    pi-app.env that build.sh rendered beside it is not there any more. Phase 0
    died on the first line that needed it. It now takes the staging directory
    from PI_IMAGE_BUILD, which build.sh already exports for the other files it
    stages, and fails loudly if that is unset.
    Phase 0 also wrote authorized_keys into a home directory belonging to an
    account that sdm's user plugin does not create until phase 1, leaving files
    no one owned. That moved to phase 1, where the account exists and the
    ownership fix-up can cover the whole home directory.
    Neither is visible to shellche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
2026-08-24 Do not assume the image already has /etc/systemd/system
    A real Raspberry Pi OS image does, so this would not have failed a build --
    but phase 0 was relying on it silently, and the new test's fixture was bare
    enough to notice. Create the directory, and give the fixture the directories
    a real image actually ships so it cannot pass by being more generous than
    the Pi.
2026-08-24 The sdm user plugin takes adduser=, not username=
    Checked against the plugin's own vldargs list rather than guessed; every
    --switch build.sh passes was checked the same way against sdm's getopt
    longopts, so this should be the last of these.
2026-08-24 Stage B died on a fused command line before it set the static IP
    Two lines had run together into
    systemctl enable redis-serversystemctl enable redis-server
    which asks systemd to enable a unit that does not exist. Under set -euo
    pipefail that took stage B down on that line -- after dpkg, but before uv,
    the venv, the server unit and, critically, the isolated static address. The
    Pi therefore booted into a healthy OS that was not on the network, which is
    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
2026-08-24 Pin every external input to the image build
    Four inputs floated: sdm from master, raspios_lite_arm64_latest, the uv
    installer, and requirements.txt ranges. An image is only debuggable if
    rebuilding it later produces the same thing; with four moving parts, "it
    worked in August and not in October" has no bisectable cause. The sdm one
    already cost this branch two builds when the user plugin's username=
    argument became adduser=.
    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
2026-08-25 Exercise real motor commands in CI
2026-08-25 Match motor pulse assertions to GPIO booleans
2026-08-25 Let the bundle install on Desktop, and unbreak the redis line
    Stage B died on a real Pi at dpkg:
    Errors were encountered while processing:
    .../bundle/debs/python3-rpi.gpio_0.7.1~a4-1.2_arm64.deb
    Current Raspberry Pi OS ships python3-rpi-lgpio, a shim offering the
    RPi.GPIO API on top of lgpio because the original does not work on a Pi 5,
    and it Conflicts with python3-rpi.gpio. dpkg -i does not resolve conflicts,
    so it fails outright. The bundle is resolved in a Lite chroot, where the
    shim is absent, so the clash only appears on Desktop and Full -- exactly
    the combination CI never builds. Where the shim is installed it already
    provides the module, so drop that deb from the set and leav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
2026-08-25 Let -DiskNumber reach a card the bus filter passed over
    The flasher only accepted disks reporting USB, SD or MMC. Built-in PCIe card
    readers report SCSI -- the Realtek reader in the laptop we provision from
    does -- so autodetect found nothing, and -DiskNumber could not override it
    because it filtered through the same list. That left no way to flash a card
    on the machine you would actually be recovering from, which is the one job
    this script has.
    Split the two ideas that were tangled together. Writable is the real safety
    boundary: never the boot disk, never the system disk, never something too
    large to be removable media. Bus type only narrows autodetect, where
    guessing wrong unprompted woul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
2026-08-25 Ask Windows where Raspberry Pi Imager is instead of guessing
    The flashers looked in two hardcoded directories and told the operator to
    install Imager when it was already installed. v1 used
    "Program Files\Raspberry Pi Imager"; v2.0.11 ships
    "Program Files\Raspberry Pi Ltd\Imager", so a current install is invisible
    to both scripts. A per-user install lands somewhere else again.
    The installer registers the exe in App Paths and records InstallLocation in
    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
2026-08-25 Restore provisioning/bootstrap.ps1, overwritten by a download
    2f926c8 committed the pi-image flasher on top of the provisioning one,
    cutting it from 318 lines to 157 and destroying the SD card builder: the
    boot-partition discovery, the bundle fetch, the password prompt, all of it.
    The overwrite happened before that commit. The README's
    irm .../pi-image/bootstrap.ps1 -OutFile bootstrap.ps1
    writes to the current directory, and it was run from inside provisioning/,
    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
2026-08-25 Wait for Imager, and refuse to claim a card we never wrote
    The flasher printed "Done. Put the media in the Pi and switch it on" over a
    card it had not touched. The Pi booted the old install, which still answered
    on the same static address, so the only symptom was a missing service.
    rpi-imager.exe is a GUI-subsystem binary. PowerShell's `&` launches those and
    returns immediately, so the write had barely begun when the next line ran;
    $LASTEXITCODE still held 0 from the download, the failure check passed, and
    the script reported success. Imager ships rpi-imager-cli.cmd for exactly this
    reason, and that wrapper's own comment says so: "necessary because it is
    compiled as GUI application, and Win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
